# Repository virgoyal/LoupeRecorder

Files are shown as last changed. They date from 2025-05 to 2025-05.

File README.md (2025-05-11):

# Surgical Loupe Video Recording System
# Technical Documentation

**Modlab UPenn**  
**April 2025**

## Abstract
This document outlines the development of a specialized video recording system designed for integration with surgical loupes, developed for Dr. Sonul Mehta from Penn Medicine through Modlab UPenn. The project addresses the need for micro-surgeons performing delicate procedures to record their activities with minimal interference to their work. The system utilizes FPV (First Person View) drone technology adapted for medical applications, allowing surgeons to record procedures from their perspective while maintaining sterility in the operating environment through a remote control system.

## 1 System Requirements
Based on the project brief from Modlab UPenn (January 2025) and subsequent development decisions:
* **Lightweight Design**: Minimizing additional weight on surgeon's loupes
* **Non-Obstructive**: Must not block or impair the surgeon's field of view
* **High Resolution**: 4K video capture for effective post-processing zoom
* **Sterile Operation**: Some way to operate the camera without compromising the sterility of the OR
* **Minimum 1-Hour Runtime**: Battery life sufficient for standard procedures

## 2 System Concept
After exploring options to develop a custom recording system from scratch, we determined that achieving the required resolution in a lightweight, compact package suitable for loupe mounting would be infeasible with our resources. Commercial FPV (First Person View) drone camera systems emerged as an ideal alternative, offering excellent video quality in an extremely compact form factor.

However, these systems presented an integration challenge as they're typically controlled through a drone's flight controller (FC). Our solution was to interface with the camera by simulating physical button presses using a CD4066 IC analog switch. By connecting to exposed pads of the switches on the camera's PCB, we could remotely trigger camera functions through our custom control system while maintaining the camera's original functionality and performance characteristics.

Initially, voice command control was proposed for sterile operation, but was abandoned due to reliability issues in the OR environment. A remote control solution was settled on as a more reliable alternative, with sterility maintained by covering the remote controller with new sterile film for each procedure.

This approach allowed us to leverage existing high-performance technology while adapting it to the specific requirements of a surgical environment. The system utilizes this modified FPV drone technology and aims to allow surgeons to record procedures from their perspective while maintaining sterility through a wireless remote control system.

## 3 Hardware Components

### 3.1 Camera System
* **Camera**: RunCam Split 4
  * **Dimensions**: 29mm × 29mm (lens module), 14mm × 14mm (PCB)
  * **Weight**: 10.2g
  * **Video Capabilities**: 4K@30fps, 2.7K@60fps, 2.7K@50fps, 1080P@60fps
  * **Storage Capacity**: Supports up to 128GB microSD card (U3 recommended)
  * **Field of View (FOV)**: 140°
  * **Sensor**: SONY 13MP
  * **Video Format**: MP4
  * **Storage Efficiency**: 4K 30fps footage requires approximately 83MB for 33 seconds of video
    * This equals about 151MB per minute or 9.1GB per hour
    * With 128GB storage, this provides approximately 14 hours of continuous 4K recording

The camera mounts directly to the surgical loupes, adding minimal weight to the surgeon's equipment. Testing in surgical lighting conditions showed we need to play with brightnesss and contrast in post editting to achieve adequate detail for post-procedure analysis.

### 3.2 Control System
* **Main Controller**: ESP32 C3 SuperMini
  * **Wireless Protocol**: ESP-NOW for low-latency communication
  * **Connectivity**: Interfaces with the camera control circuit via GPIO pins
  * **Power Draw**: Approximately 100mA during active transmission
  * **Dimensions**: 34.3mm × 20.3mm
  * **Weight**: 3g

* **Remote Controller**: Secondary ESP32 C3 SuperMini
  * **Design**: Housed in a compact 3D-printed case with physical buttons
  * **Interface**: Two tactile buttons for core functions (Start/Stop Recording, Mode Switch)
  * **Range**: Yet to be tested
  * **Sterility Solution**: Designed to be wrapped in sterile film for OR use

The ESP-NOW protocol was selected for its reliability in electromagnetically noisy environments like operating rooms. The wireless connection exhibited consistent performance in testing, with no noticeable latency between button press and response.

### 3.3 Circuit Components
* **Analog Switch**: CD4066 IC
  * **Function**: Simulates physical button presses on the camera
  * **Operation Voltage**: 5V 
  * **Control Method**: Digital signals from ESP32 activate switches corresponding to camera buttons

* **Pull-up Resistors**: 10kΩ (R1 and R2)
  * **Purpose**: Prevents unwanted triggering when system is unpowered
  * **Rating**: 1/4W, standard tolerance

* **Decoupling Capacitors**: 0.1µF (C1 and C2)
  * **Purpose**: Provides noise filtering and debounce protection for clean switching
  * **Type**: Ceramic, low ESR

#### 3.3.1 Camera PCB Modification Process
**Tools Required:**
- Dremel rotary tool with precision cutting/grinding bit
- Magnifying glass or microscope (recommended)

**Process:**

1. Used a Dremel rotary tool on low speed to carefully remove the physical switch from the PCB
2. Ensured the exposed pads remained intact after switch removal

**Challenges Encountered:**
- The exposed pads are extremely small, requiring a soldering tip finer than what was available
- Direct soldering to these pads presents a risk of damaging the PCB with excessive heat
- Current status: Successfully removed the switch, but connection to the exposed pads remains a challenge

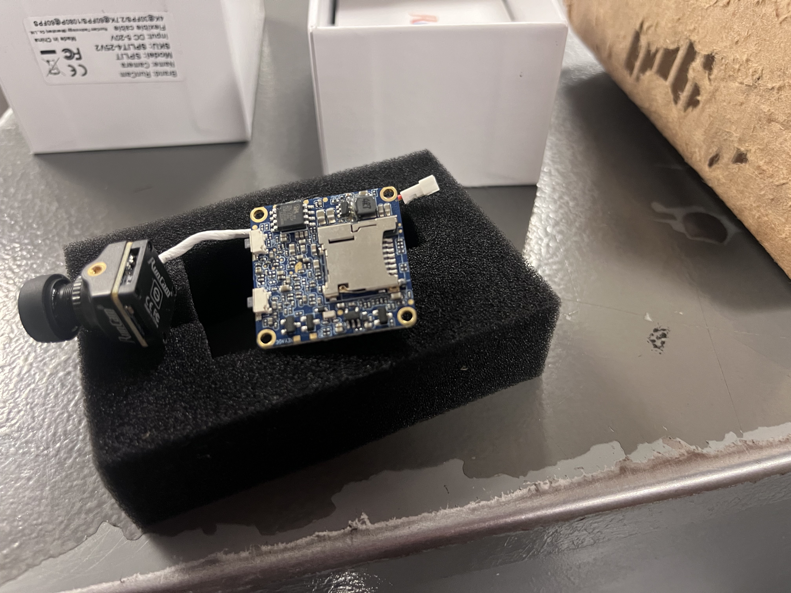
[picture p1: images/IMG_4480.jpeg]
PCB with switch

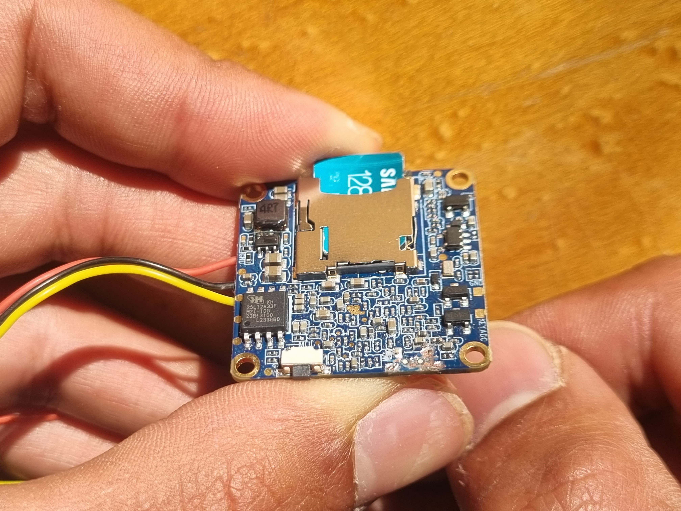
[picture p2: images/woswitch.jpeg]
PCB without switch

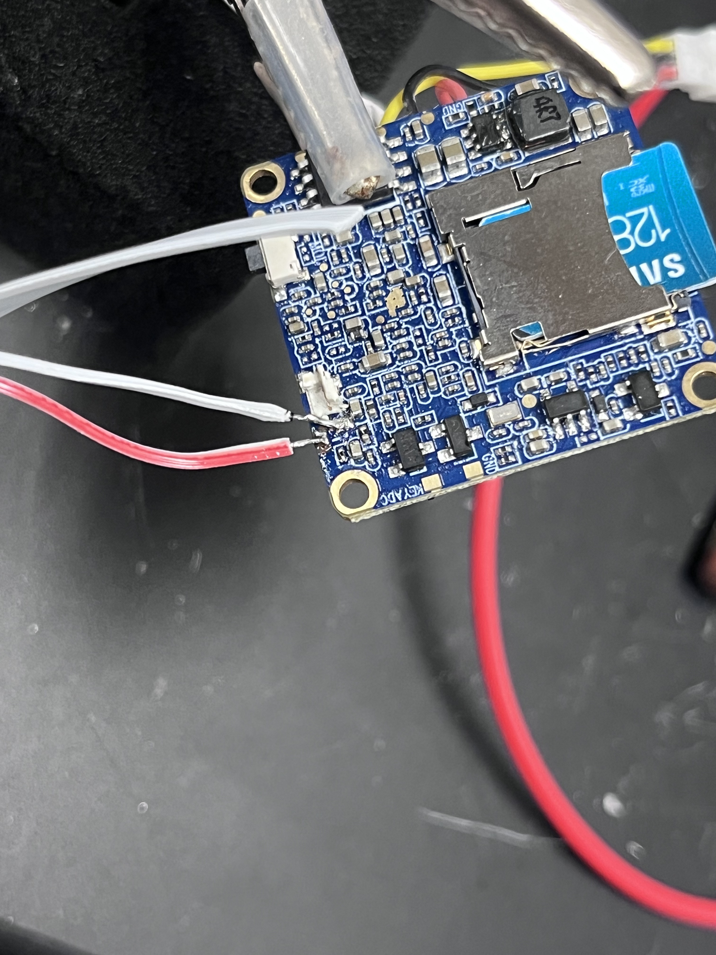
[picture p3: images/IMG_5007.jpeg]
PCB with leads soldered switch


### 3.4 Video Transmission
* **Video Transmitter**: TBS Unify Pro 5G8 V3 (RP-SMA)
  * **Operating Voltage**: 4.5 - 5.5V
  * **Supply Current**: 600mA
  * **Output Power Options**: 13dBm (25mW), 23dBm (200mW), 27dBm (500mW), 29dBm (800mW)
  * **Video Format**: NTSC/PAL
  * **Weight**: 5g (with SMA, without antenna)
  * **Connector**: RP-SMA Female Socket with screw mounting holes

* **Cooling System**: Raspberry Pi fan
  * **Dimension**: 30mm × 30mm × 7mm
  * **Operating Voltage**: 5V
  * **Current Draw**: Approximately 100mA
  * **Mounting**: Direct attachment to the electronics housing with airflow directed at the video transmitter

### 3.5 Power System
* **Power Source**: Lightweight portable power bank
  * **Capacity**: 10,000mAh
  * **Output Ports**: Dual USB-A outputs (5V, 2.1A each)
  * **Dimensions**: 115mm × 70mm × 22mm
  * **Weight**: 180g
  * **Mounting**: Belt-mounted using the custom 3D-printed housing

* **Power Distribution**:
  * **Total System Current Draw**: Approximately 0.8A (Camera + Video Transmitter + Fan + ESP32 Controllers)
  * **Estimated Runtime**: Approximately 12 hours at full load
  * **Wiring**: 24 AWG silicone wire for flexibility and durability

The power system is designed to be entirely belt-mounted, avoiding any additional weight on the surgeon's head. A single cable runs from the belt unit to the loupe-mounted camera, minimizing the impact on mobility.

### 3.6 Physical Housing
* **Camera & Electronics Mount**: Custom 3D-printed housing
  * **Material**: PLA
  * **Design Features**:
    * Compartmentalized sections for power bank, controller MCU & 4066 IC circuit, video transmitter
    * Ventilation channels for cooling

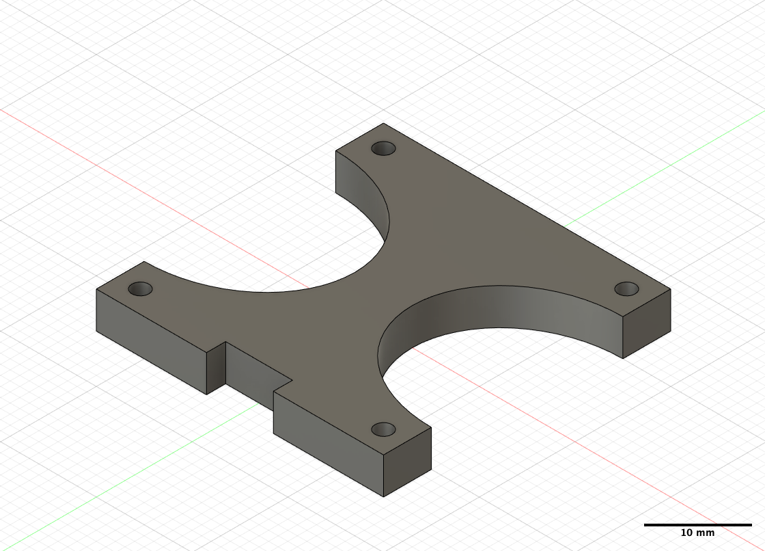
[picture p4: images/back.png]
Camera Mount Back

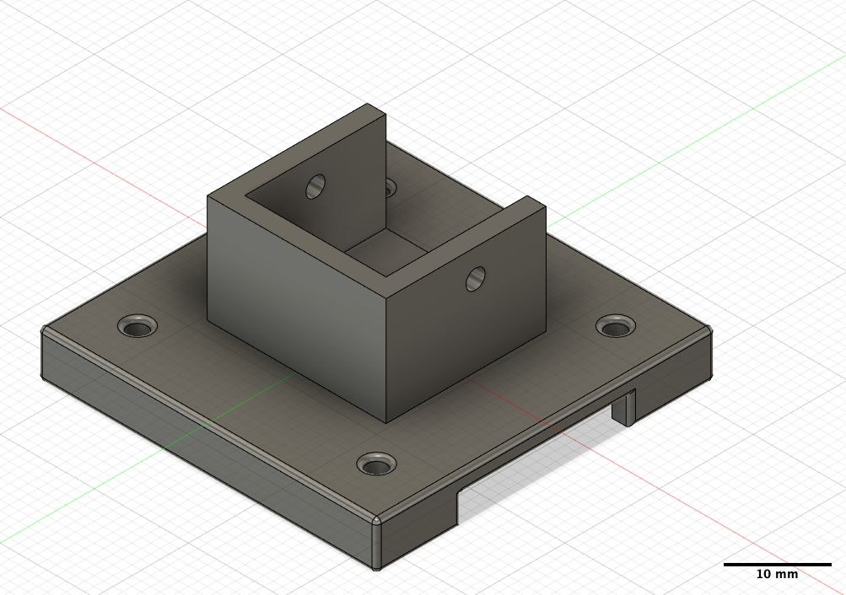
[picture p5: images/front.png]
Camera Mount Front

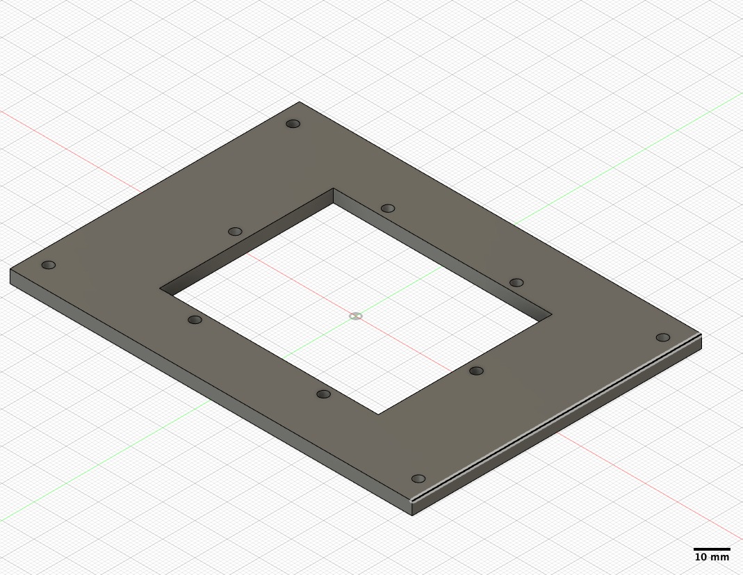
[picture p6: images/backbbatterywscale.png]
Battery Holder Back

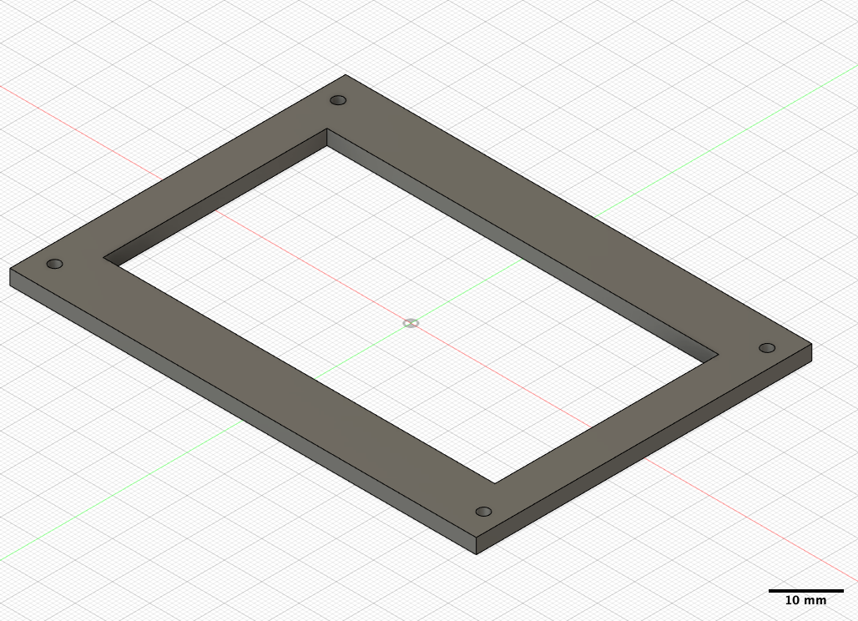
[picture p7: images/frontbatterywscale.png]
Battery Holder Front

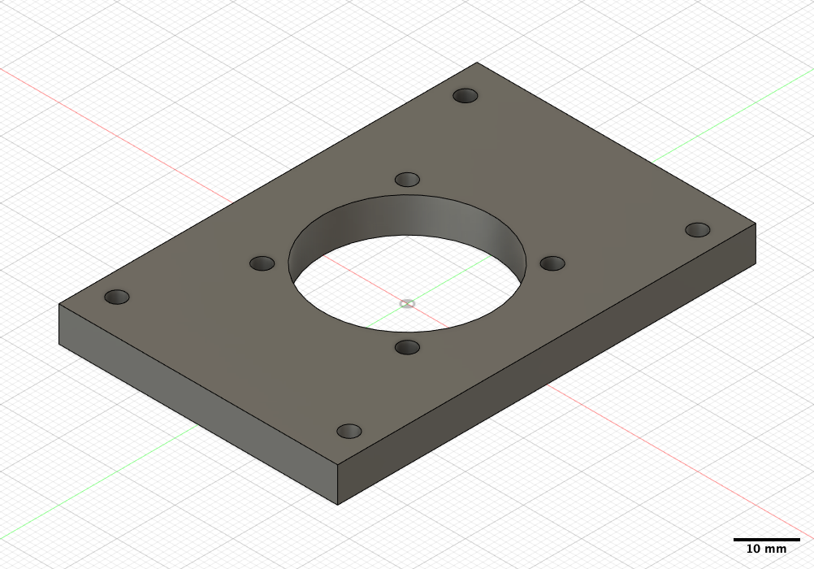
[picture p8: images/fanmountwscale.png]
Fan Mount


## 4 Circuit Design

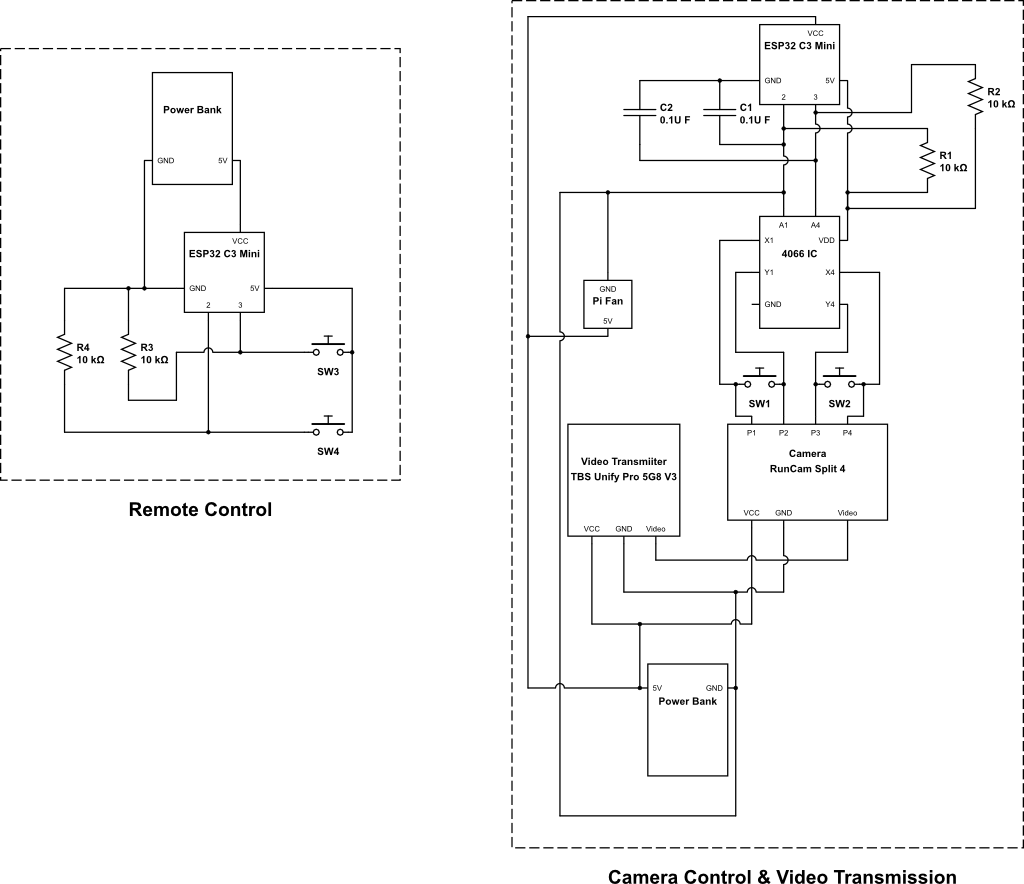
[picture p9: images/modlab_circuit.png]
Circuit

The circuit design consists of two main sections:
1. **Remote Control Circuit**: ESP32 C3 SuperMini with tactile buttons and pull-up resistors
2. **Camera Control & Video Transmission Circuit**: ESP32 C3 SuperMini connected to CD4066 IC, which interfaces with the RunCam Split 4 camera and TBS Unify Pro video transmitter

## 5 Implementation Details

### 5.1 Sterile Remote Control System
The remote control system was developed as an alternative to voice commands, which were found to be unreliable in the operating room environment. Key features include:

* **Sterile Operation**: The remote control is designed to be wrapped in fresh sterile film for each procedure
* **Simple Button Interface**: Two clearly defined buttons for core functions that can be operated while wearing surgical gloves
  * **Button 1**: Start/Stop Recording
  * **Button 2**: Mode Switch (Video/OSD settings)
* **Feedback Mechanism**: LED indicators to confirm button presses and system status

Testing was done with a mock setup where instead of controlling the camera the remote controlled two LEDs.

### 5.2 Camera Control Interface
The RunCam Split 4 is interfaced through its button inputs. We propose the CD4066 IC act as an electronic switch, simulating button presses when triggered by the MCU based on remote commands. This approach will maintain the original camera functionality while adding remote control capability.

The button simulation process will work as follows:
1. The remote control sends a command via ESP-NOW to the main controller
2. The main controller activates the appropriate switch in the CD4066 IC
3. The CD4066 connects the corresponding pads on the camera PCB
4. The camera interprets this as a physical button press

### 5.3 Wireless Command Protocol
Commands from the remote control unit are transmitted to the main MCU via ESP-NOW, which provides:
1. Low-latency communication (important for responsive camera control)
2. Reliable operation in the electromagnetically noisy OR environment
3. Error checking to ensure command integrity
4. Simple pairing process for quick setup

The ESP-NOW implementation uses a basic message structure:
```
struct cmd_data {
  uint8_t command;  // 0: No command, 1: Record, 2: Mode switch
  uint8_t state;    // 0: Button released, 1: Button pressed
};
```

This efficient protocol minimizes transmission overhead and power consumption.

### 5.4 Thermal Considerations
The video transmitter generates significant heat during operation. The Pi fan provides active cooling to prevent hardware damage, ensuring consistent performance throughout extended procedures.

Temperature testing is yet to be done on the system.

## 6 Advantages and Applications
* **Procedure Documentation**: High-quality 4K recording for training and review
* **Remote Consultation**: Real-time feed sharing with specialists
* **Medical Education**: Creation of educational materials from surgeon's perspective
* **Patient Communication**: Visual aids for explaining procedures to patients

## 7 Future Enhancements
* **Motorized Tilt System**: Implementation of remotely controlled camera angle adjustment
* **Extended Battery Life**: Development of lightweight power solutions for 12+ hour runtime
* **Addition of Audio Recording**: Voice annotation capability during procedures
* **Cloud Backup**: Automatic backup for video recordings

## 8 Prototype Performance Assessment
The current prototype demonstrates the following performance characteristics relative to the original requirements:

* **Lightweight Design**: Success 
* **Non-Obstructive**: Partial success - we were able to model a camera mount with a minimal design but to have a reliable mount we would have to have access to the loupe.
* **High Resolution**: Successful - 4K video capture provides excellent detail for post-processing
* **Sterile Operation**: Partial success - Remote control using CD4066 IC on a mock circuit with 2 LEDs works but since we havent been able to silder to the exposed switch pads on the camera PCB we dont have a fully remote recording system yet 
* **Minimum 1-Hour Runtime**: Successful - System achieved 1 hour of runtime without hurting any components due to overheating or running out of storage.

**Challenges and Limitations**:
PCB connection reliability remains the primary technical challenge. Even when I was able to solder the leads onto the PCB it was too close to a capacitor and the camera kept shorting and power cycling.

## 9 Conclusion
This surgical loupe video recording system represents an innovative application of consumer electronics technology in a medical setting. By adapting FPV drone equipment for surgical use, the system provides high-quality video recording capabilities controlled through a sterile remote interface, allowing surgeons to document procedures without compromising sterility or adding significant weight to their equipment.

The design prioritizes the specific needs of micro-surgeons performing delicate procedures while offering a pathway to enhanced functionality through future iterations. The system is currently in the prototype phase with core functionality implemented and testing underway in controlled environments.

## Appendix A: Bill of Materials

| Component | Specification | Supplier | Cost |
|---|---|---|---|
| RunCam Split 4 | 4K FPV Camera | Amazon |  $109.00 |
| ESP32 C3 SuperMini (×2) | Development Board | Amazon |  $5.99 each |
| TBS Unify Pro 5G8 V3 (SMA) | Video Transmitter | GetFPV | $39.99 |
| CD4066 IC | Quad Bilateral Switch (20pcs) | Amazon |  $7.99 |
| SAMSUNG EVO Select microSD | Memory Card + Adapter, 128GB | Amazon |  $13.99 |
| SoloGood FPV Monitor | 4.3inch with DVR 5.8Ghz 40CH 800×480 | Amazon  | $62.99 |
| Smaller Antennas | Compact 5.8GHz | Amazon  | $7.00 |
| Cooling Fans | 5V 30mm | Amazon  | $7.00 |

## Appendix B: Special Tools Required
* Dremel rotary tool with precision bits
* Soldering iron with micro-tip (smaller than standard tips)

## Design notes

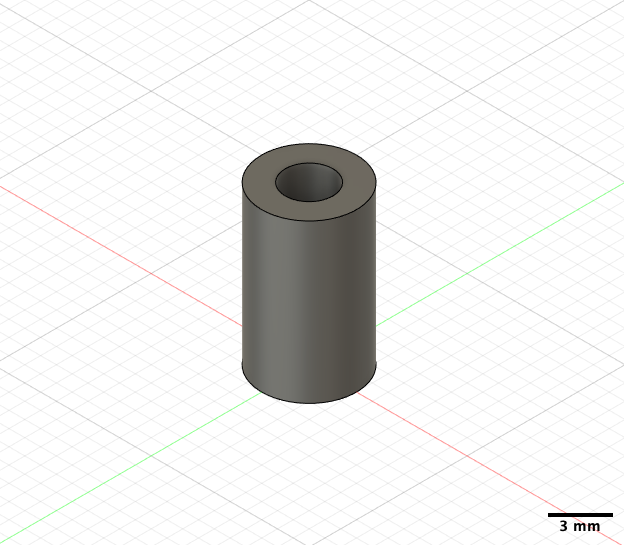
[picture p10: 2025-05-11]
images/peg10wscale.png

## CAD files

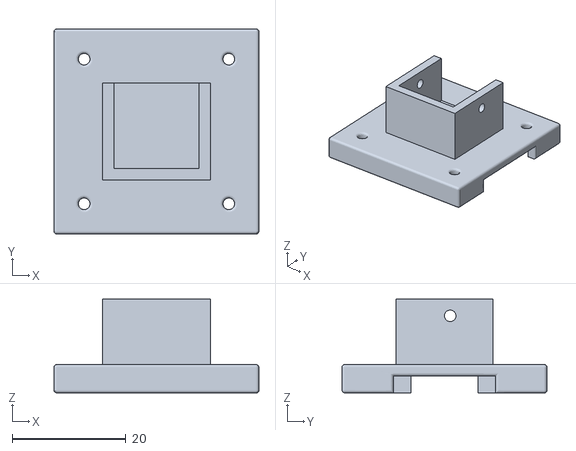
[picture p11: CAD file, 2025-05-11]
stl_files/FULLTOP v1.stl
36.0 x 36.0 x 16.5

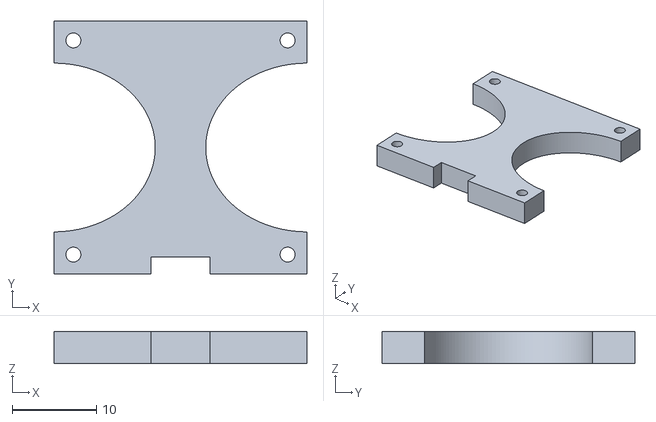
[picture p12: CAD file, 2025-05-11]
stl_files/base_plate.stl
30.0 x 30.0 x 3.81

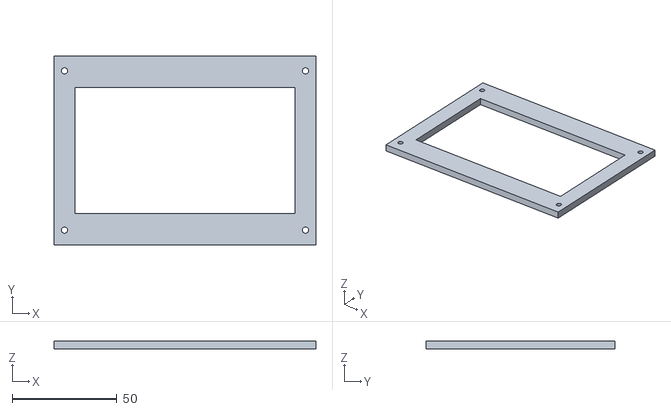
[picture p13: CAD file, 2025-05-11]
stl_files/frontbattery v1.stl
125.0 x 90.0 x 4.00

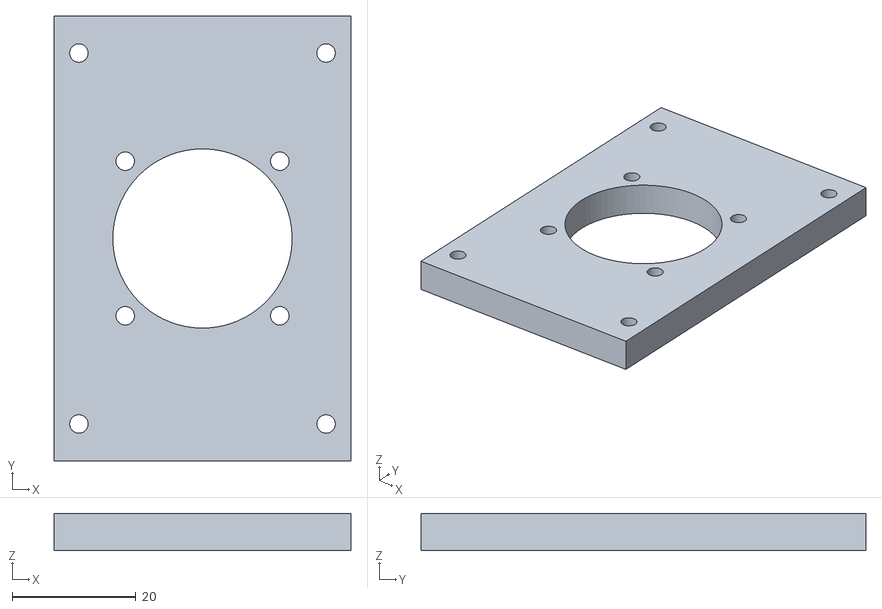
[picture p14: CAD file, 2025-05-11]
stl_files/fanmountwpegs v1.stl
48.0 x 72.0 x 6.00

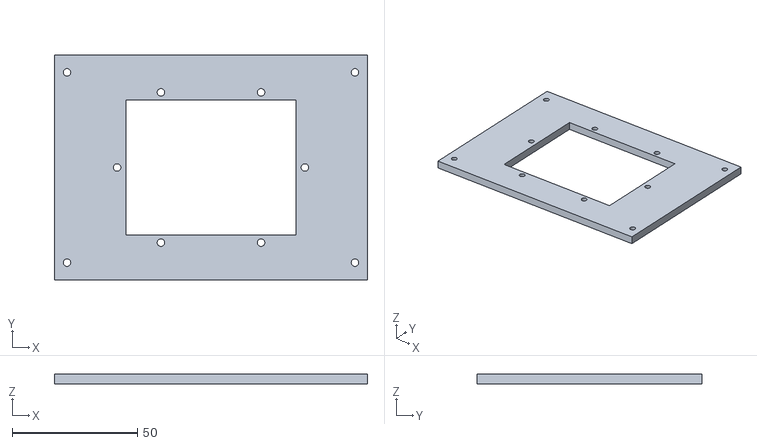
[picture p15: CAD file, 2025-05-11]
stl_files/backbattery v1.stl
125.0 x 90.0 x 4.00

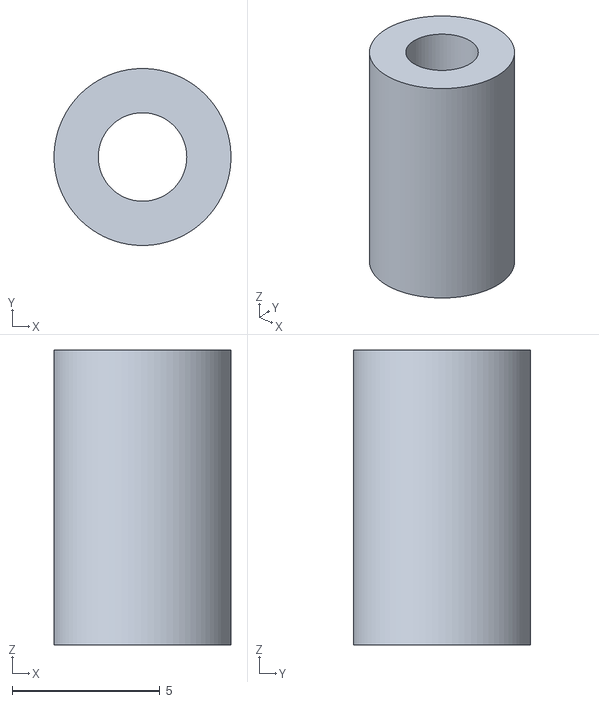
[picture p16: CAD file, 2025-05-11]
stl_files/peg10 v1.stl
6.00 x 6.00 x 10.0

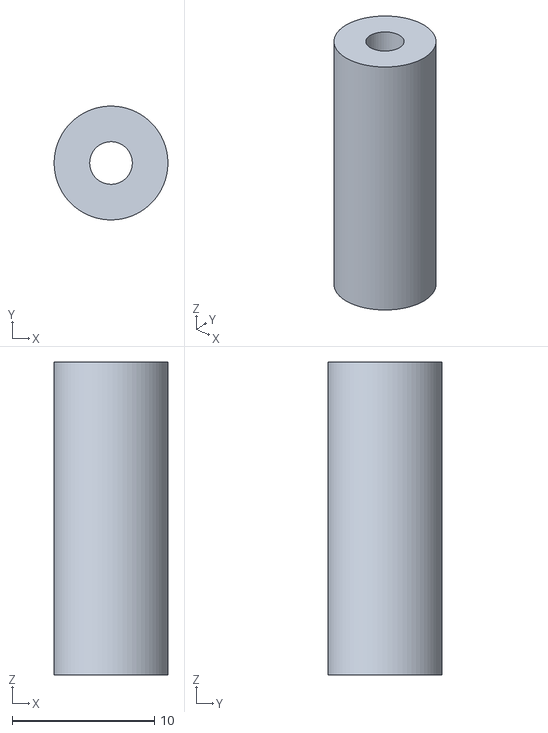
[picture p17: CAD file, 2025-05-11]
stl_files/peg22 v2.stl
8.00 x 8.00 x 22.0
